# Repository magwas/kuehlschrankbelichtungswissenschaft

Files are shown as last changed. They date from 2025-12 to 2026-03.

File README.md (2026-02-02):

# Kühlschrankbelichtungswissenschaft

Kühlschrankbelichtungswissenschaft means "fridge lighting science".
It is an open hardware, open source steampunk control unit for agriculture projects, with two set of the following features:

- controlled 220V mains plug for a lamp
- humidity sensor as a 3.5mm audio socket
- CO2 sensor
- two temperature sensors
- controlled 12V barrel outlets for ventillation, cooling, nutrient and heating

The CO2 and temperature sensors are connected using RJ11 connectors with the following pinout:

1. GND (green)
2. 3V3 (green-white)
3. SDA (brown)
4. SCL (brown-white)
5. 5V (red)
6. OneWire (red-white)

The ground of the connectors for RJ11 is controlled, as the CO2 sensor used have a fix I2C address.

The circuit design is in the conteroller directory.

The schematics layout looks as it is to make it easier to implement it as a freeform circuit.
This is the reason there is no PCB design. Of course you are welcome to build it on a PCB.
A two-sided PCB should be adequate for the job, there is nothing placement-critical there.

I did not put the USB-c cable between the board and the connector on the chassis on the circuit design,
simply because the symbol I use does not contain it.

## SOFTWARE INSTALLATION

The software uses ESP IDF, and the msglib library.
Install ESP IDF as documented at https://docs.espressif.com/projects/esp-idf/en/latest/esp32/get-started/
Clone msglib to a convenient place, like
```
mkdir ~/build
cd ~/build
git clone https://github.com/magwas/msglib
```

to build, flash and monitor the software, plug in the board to the USB, export MESSAGING_LIB with the location where you cloned it, activate ESP IDF, and run idf.py build, something like

```
export MESSAGING_LIB=$HOME/build/msglib
. ~/.espressif/tools/activate_idf_v5.5.2.sh ~/idf-esp-activate
idf.py -p /dev/ttyACM0 build flash monitor
```

## HARDWARE FABRICATION

The mechanical design is in the FreeCad model box.CFStd. I have a Snapmaker 2, so the CNC jobs use the marlin preprocessor.

The fixjobs.sh script

- fixes the output of the preprocessor (marlin emits M3 S100, snapmaker understands M3 P100, and the comments are in different form)
- removes all Z movement from the laser engraving jobs, replacing some of the to gcode turning the laser off and on again.

IMPORTANT: the engraving job fix translates movement to Z=26 (G0 Z26.000) to turning the laser off, and Z=21 (G0 Z21.000) to turning it on.
Make sure that the heights and depths of the engraving job correspont to these if you modify it.

postprocess all of the CNC jobs. The "Stock Prepare" job is for preparation of the stock on my own machine, you might of course choose other ways to fix your stock.
run fixjobs.sh or something equivalent for your setup.
the file cnc-workflow contains the instructions to do the milling and engraving. It contains the sizes of the stocks. I recommend to use some hardwood. I used white acacia, as I love that wood. You will need a 128x86 and 246x86 mm sheet of 4mm tempered glass.
Populate the dashboard with components. I try to recall here what I was using. Be aware that they are mostly cheap noname parts. Which means you can probably buy ones with similar sizes.

- For the mains plugs, I cannibalized some LEGRAND SUNO plugs, by removing everything above the bottom plastic and metal parts, and trimming down the plastic parts, keeping the tabs which open the electrodes for the assembly.
- The main switch is a 22x30 standard switch.
- The 12V barrel connectors I obtained are for 12mm diameter fine thread. I did not want to buy a tap for that, instead I made the holes the size such that they fit snuggly.
 - Vents are standard PC ventillators
 - The cooling pumps are 12V pumps I bought on eBay. The cooling is a mix of 6mm outer diameter copper and 6mm inner diameter silicone tubes.
 - The nutrient dosage pumps are just like the cooling pumps.
 - I actually do not yet have heating. I plan to coil up some heating wires for that purpose on some ceramics.
- The USB-C connector is a noname one which fits into the 3.5x10mm hole and its length is 15mm. I could not find a datasheet for a similar one.
- The connectors for the humidity sensors are standard 3.5mm audio jacks. They are actually the tye of swinging connector wher the round connector part is fixed to the anti-fracture housing with a thread. I use just the inner part. The humidity sensors are just steel rods (~10cm sut from bicycle spokes) placed 1 cm apart.
- The design now have just a simple hole for the wifi antenna, as I am currently waiting for the board wersion which comes with a connector for it.
- The RJ11 connectors are the plain usual 90 degree ones.

All other components (and most of the aboveones ) are in the BOM of the circuit.

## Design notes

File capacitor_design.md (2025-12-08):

---
mainfont: DejaVu Serif
sansfont: DejaVu Sans
monofont: DejaVu Sans Mono
mathfont: DejaVu Math TeX Gyre
---
###  Geometry & Electrical Performance Summary
The design is based on a wound roll of aluminum foil electrodes separated by paper dielectric, with a target capacitance of 10 µF and a foil width of 0.3 meters. The required physical dimensions change significantly based on the paper thickness and the composite dielectric constant (εᵣ ≈ 3.2) of the oil-impregnated paper.

| Parameter | Using 30 g/m² Paper (~40 µm thick) | Using 60 g/m² Paper (~75 µm thick) | Notes |
| :--- | :--- | :--- | :--- |
| **Foil Length Required** | ~47 meters | ~88 meters | For one of the two foil strips. |
| **Approx. Outer Diameter** | ~6.3 cm | ~11.2 cm | Estimated from winding volume around a 1 cm core. |
| **Estimated Safe DC Voltage** | **300 - 400 V** | **550 - 750 V** | **Critical:** This is a *practical safe voltage*, estimated at 20-30% of the material's theoretical limit to account for imperfections. |
| **Material Breakdown Strength** | Up to **30 kV/mm** (theoretical) | | Conservative estimate for well-impregnated, dry paper-oil composite. The oil displaces air and can increase breakdown strength significantly. |

###  Preparation & Treatment Steps
The process is divided into three main phases, with the CaO treatment being a highly experimental and challenging addition.

1.  **Core Construction & Drying**
    *   **Wind the Capacitor:** Assemble the dry, unimpregnated roll using the specified lengths of aluminum foil and paper.
    *   **Condition the Roll:** Bake the entire wound roll in an oven at 105-110°C for several hours to drive out absorbed moisture. Cool it in a dry environment.

2.  **Oil Treatment with CaO (Experimental & High-Risk)**
    *   **Purpose:** To chemically bind residual water in the olive oil (**CaO + H₂O → Ca(OH)₂**) and neutralize free fatty acids.
    *   **Critical Challenge:** The reaction creates a fine, insoluble **Calcium Hydroxide [Ca(OH)₂]** powder suspended in the viscous oil, which is extremely difficult to remove completely.
    *   **Recommended Separation Method:** **Vacuum Filtration** with a **filter aid** (like diatomaceous earth) is the most effective practical method. Simple decantation will not work, and centrifugation may be insufficient.
    *   **Major Risk:** Any remaining Ca(OH)₂ in the oil can dissociate into conductive ions, severely degrading the dielectric's insulating properties and likely ruining the capacitor.

3.  **Final Impregnation & Sealing**
    *   Immediately after drying, submerge the capacitor roll in the treated, warm olive oil in a vacuum chamber (or as close to a vacuum as possible) to ensure the oil fully penetrates the paper layers.
    *   Seal the impregnated capacitor in an airtight container to prevent moisture re-absorption.

###  Key Takeaways & Recommendations
*   **Trade-off:** Thicker paper (60 g/m²) allows for a much higher voltage rating but results in a capacitor that is nearly twice as large.
*   **Voltage is Theoretical:** The calculated safe voltages are optimistic estimates. Real-world performance depends entirely on the perfection of your drying, impregnation, and sealing.
*   **CaO is Problematic:** The CaO treatment step introduces significant complexity and risk of failure. For a more reliable project, the recommended alternatives are to use a **non-contact "tea bag" method** with silica gel (desiccant) and calcium carbonate (acid scavenger), or to use a purpose-made dielectric fluid like transformer oil.

Glass pipe: https://webaruhaz.lombik.hu/uvegcsovek?product_id=1785

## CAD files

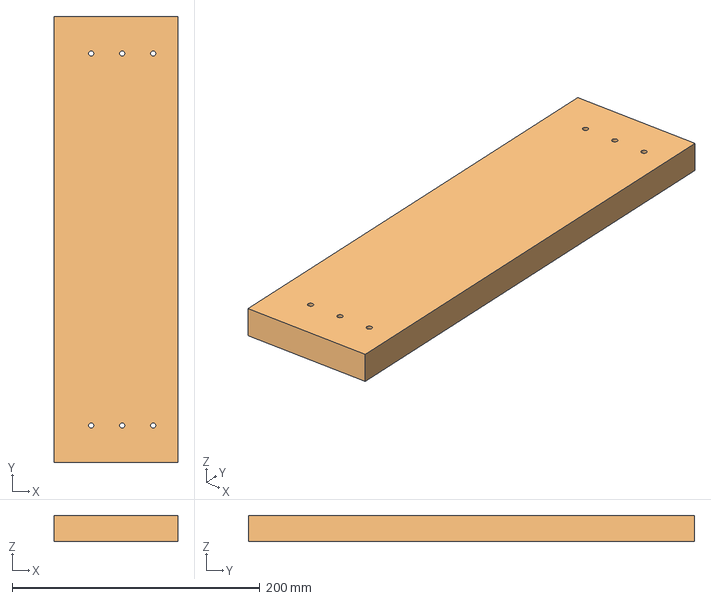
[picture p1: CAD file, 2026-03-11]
box.FCStd
100.0 x 360.0 x 21.0 mm
Stock-The Stock004
Stock-The Stock006

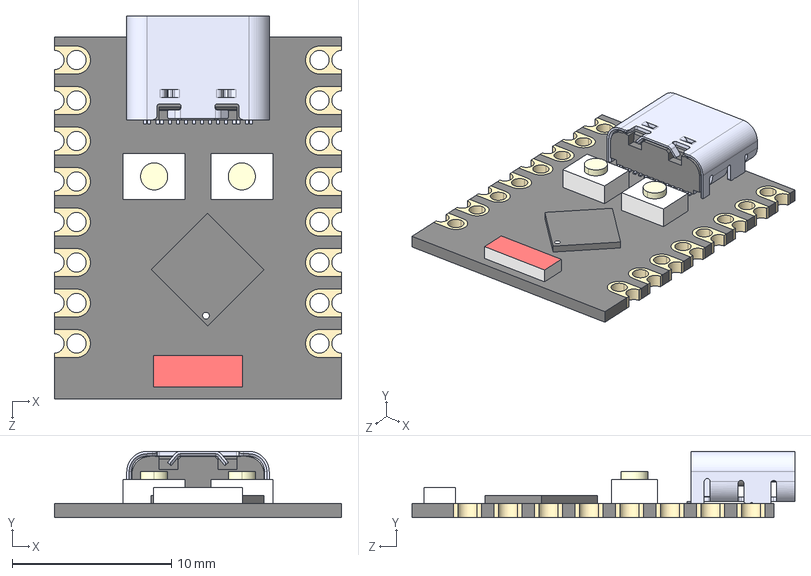
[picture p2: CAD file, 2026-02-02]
controller/parts/ESP32-C3_SUPERMINI_TH.step
18.0 x 4.16 x 24.0 mm
Board c3mini
USB C
components (other)^ESP32-C3 SuperMini

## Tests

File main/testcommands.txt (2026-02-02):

astable 1 -1 4
astable 0 -1 1
astable 1 0 10
astable 2 0 1000
astable 3 0 1000
astable 5 0 10
astable 6 0 0
astable 0 0 1

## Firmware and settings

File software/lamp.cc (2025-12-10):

#include <Arduino.h>
#include "lamp.h"
#include "userinterface.h"

void Lamp::setPPF(int ppf65, int ppf18) {
  if(!isLampOn)
    Lamp::on();
  Lamp::setPPF65(ppf65);
  Lamp::setPPF18(ppf18);
}

void Lamp::setlamp(int port, float ppf) {
  int value = ppf*PPF2DUTYCYCLE_MULTIPLIER;
  char buffer[PAYLOAD_LENGTH];
  sprintf(buffer,"setting %u to %f (%u)",port,(double)ppf,value);
  systemQueue.send(MessageType::Console,buffer);
  analogWrite(port,value);
}

void Lamp::setPPF18(int ppf18) {
  if(ppf18>PPF18_MAX)
    ppf18 = PPF18_MAX;
  if(ppf18>=PPF_MIN*4) {
    float perlamp = ppf18/4.0;
      setlamp(PWM_18_1,perlamp);
      setlamp(PWM_18_2,perlamp);
  } else {
      setlamp(PWM_18_1,ppf18/2.0);
      setlamp(PWM_18_2,0);
  }
}


void Lamp::setPPF65(int ppf65) {
  if(ppf65>PPF65_MAX)
    ppf65 = PPF65_MAX;
  if(ppf65>=PPF_MIN*5) {
    float perlamp = ppf65/5.0;
      setlamp(PWM_65_1,perlamp);
      setlamp(PWM_65_2,perlamp);
      setlamp(PWM_65_3,perlamp);
  } else if(ppf65>=PPF_MIN*4) {
    float perlamp = ppf65/4.0;
      setlamp(PWM_65_1,perlamp);
      setlamp(PWM_65_2,perlamp);
      setlamp(PWM_65_3,0);
  } else if(ppf65>=PPF_MIN*3) {
    float perlamp = ppf65/3.0;
      setlamp(PWM_65_1,perlamp);
      setlamp(PWM_65_2,0);
      setlamp(PWM_65_3,perlamp);
  } else if(ppf65>=PPF_MIN*2) {
    float perlamp = ppf65/2.0;
      setlamp(PWM_65_1,perlamp);
      setlamp(PWM_65_2,0);
      setlamp(PWM_65_3,0);
  } else  {
      setlamp(PWM_65_1,0);
      setlamp(PWM_65_2,0);
      setlamp(PWM_65_3,ppf65);
  }
}

void Lamp::on() {
  analogWrite(PWM_65_1,0);
  analogWrite(PWM_65_2,0);
  analogWrite(PWM_65_3,0);
  analogWrite(PWM_18_1,0);
  analogWrite(PWM_18_2,0);
  digitalWrite(LAMP_RELAY,HIGH);
  for(int i=0;i< 256;i++){
    analogWrite(PWM_MAINS,i);
    delay(20);
  }
  isLampOn = 1;
}

void Lamp::off() {
  digitalWrite(LAMP_RELAY,LOW);
  for(int i=255;i>=0;i--){
    analogWrite(PWM_MAINS,i);
    delay(20);
  }
  delay(1000);

  analogWrite(PWM_65_1,0);
  analogWrite(PWM_65_2,0);
  analogWrite(PWM_65_3,0);
  analogWrite(PWM_18_1,0);
  analogWrite(PWM_18_2,0);
  isLampOn = 0;
}

void Lamp::setCommand(Message *msg) {
    CommandPayload *payload = (CommandPayload *)msg->payload;
    lamp.setPPF(payload->arg1,payload->arg2);
}

void Lamp::relayCommand(Message *msg) {
    CommandPayload *payload = (CommandPayload *)msg->payload;
    digitalWrite(LAMP_RELAY,HIGH);
    delay(payload->arg1);
    digitalWrite(LAMP_RELAY,LOW);
}

void Lamp::onOffCommand(Message *msg) {
    CommandPayload *payload = (CommandPayload *)msg->payload;
    switch(payload->arg1) {
        case 0:
            lamp.off();
            break;
        case 1:
            lamp.on();
            break;
        default:
            systemQueue.send(MessageType::Console,"0: off, 1:on");
    }
}

Lamp::Lamp() {
    systemQueue.registerListener(MessageType::Set,&setCommand);
    systemQueue.registerListener(MessageType::Relay,&relayCommand);
    systemQueue.registerListener(MessageType::Lamp,&onOffCommand);
}
Lamp lamp;

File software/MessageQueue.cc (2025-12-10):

#include "MessageQueue.h"
#include <string.h>

void spinlock_enter(volatile int *lock) {
    (*lock)++;
    while(1!=(*lock));
}
void spinlock_exit(volatile int *lock) {
    (*lock)--;
}

void MessageQueue::send(Message *messageP) {
    spinlock_enter(&messageInProgress);
    int oldTail = messageQueueTail;
    messageQueueTail = (messageQueueTail+1)%MSG_QUEUE_LENGTH;
    memcpy(&(messageQueue[oldTail]),messageP,sizeof(Message));
    spinlock_exit(&messageInProgress);
}

void MessageQueue::send(MessageType type, char value) {
    spinlock_enter(&messageInProgress);
    int oldTail = messageQueueTail;
    messageQueueTail = (messageQueueTail+1)%MSG_QUEUE_LENGTH;
    messageQueue[oldTail].type=type;
    messageQueue[oldTail].payload[0]=value;
    spinlock_exit(&messageInProgress);
}

void MessageQueue::send(MessageType type, const char* value) {
    spinlock_enter(&messageInProgress);
    int oldTail = messageQueueTail;
    messageQueueTail = (messageQueueTail+1)%MSG_QUEUE_LENGTH;
    messageQueue[oldTail].type=type;
    memcpy(messageQueue[oldTail].payload,value,PAYLOAD_LENGTH);
    spinlock_exit(&messageInProgress);
}

void MessageQueue::send(MessageType type, const __FlashStringHelper* value) {
    spinlock_enter(&messageInProgress);
    int oldTail = messageQueueTail;
    messageQueueTail = (messageQueueTail+1)%MSG_QUEUE_LENGTH;
    messageQueue[oldTail].type=type;
    memcpy_P(messageQueue[oldTail].payload,value,PAYLOAD_LENGTH);
    spinlock_exit(&messageInProgress);
}

void MessageQueue::send(MessageType type, float value) {
    spinlock_enter(&messageInProgress);
    int oldTail = messageQueueTail;
    messageQueueTail = (messageQueueTail+1)%MSG_QUEUE_LENGTH;
    messageQueue[oldTail].type=type;
    *((float*) (messageQueue[oldTail].payload))=value;
    spinlock_exit(&messageInProgress);
}

void MessageQueue::send(MessageType type, int value) {
    spinlock_enter(&messageInProgress);
    int oldTail = messageQueueTail;
    messageQueueTail = (messageQueueTail+1)%MSG_QUEUE_LENGTH;
    messageQueue[oldTail].type=type;
    ((int *)messageQueue[oldTail].payload)[0]=value;
    spinlock_exit(&messageInProgress);
}

Message* MessageQueue::receive() {
    if(messageQueueTail == messageQueueHead)
        return NULL;
    while(messageInProgress!=0);
    int oldHead = messageQueueHead;
    messageQueueHead = (messageQueueHead+1)%MSG_QUEUE_LENGTH;
    return &(messageQueue[oldHead]);
}

int MessageQueue::registerListener(MessageType type,Listener listener) {
    for(int i=0;i<LISTENERS_COUNT_MAX;i++) {
        if(listeners[i].type==MessageType::None) {
            listeners[i].type = type;
            listeners[i].listener = listener;
            return i;
        }
    }
    return -1;
}

int MessageQueue::unregisterListener(MessageType type,Listener listener) {
    for(int i=0;i<LISTENERS_COUNT_MAX;i++) {
        if(listeners[i].type==type && listeners[i].listener == listener) {
            listeners[i].type = MessageType::None;
            return i;
        }
    }
    return -1;
}
int MessageQueue::dispatch(Message *msg) {
    int count = 0;
    for(int i=0;i<LISTENERS_COUNT_MAX;i++) {
        if(listeners[i].type==msg->type) {
            (*(listeners[i].listener))(msg);
            count++;
        }
    }
    return count;
}

MessageQueue systemQueue;

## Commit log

2025-11-08 initial checkin
    [controller.kicad_pcb, controller.kicad_sch, led.kicad_pcb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]
2025-11-08 deleted unused schematic files
    [leds.kicad_sch, power.kicad_sch, relays.kicad_sch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]
2025-11-10 made symbols and footprint relative to project
    [B7B-PH-K-S.step, ESP32-S3-DEVKITC-1-N8R8.step, IPS70R1K4P7SAKMA1.stp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]
2025-11-15 schematics with 5050 leds ready
    [ESMR401VSN102MA50S.stp, G6DN-1A_DC4.5.stp, HCTI-220-5.8.stp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]
2025-11-16 using single and dual top switch current driver circuits
    [G6DN-1A_DC5.stp, LM2903P.stp, led.kicad_sch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]
2025-11-17 RTC added
    [BAT-HLD-005-THM.stp, MCP7940N-I_P.stp, led.kicad_sch]
2025-11-17 led pcb designed
    [SMCJ1.5KE440A-TP.stp, led.kicad_pcb, leds18k_1.kicad_sch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]
2025-11-19 changed measurement resistor in current driver
    [led.csv, top_switch.kicad_sch]
2025-11-20 NDBG504F3950B1F thermistor calibration data and temperature calculation
2025-11-20 dumped soil humidity sensor design to soilHumidity.cc
2025-12-08 top switch, capacitor design doc
    [TLP240A_F.stp, top_switch.kicad_sch]
2025-12-15 compile errors, battery backup, restruct
    - compile errors on lack of #defines
    - clock battery backup configured
    - 1sec interrupt moved to clock, housekeep runs on message
    - console messages instead of printfs
2025-12-19 moved device drivers and services to library
2025-12-19 relayed lamp project started
2026-01-17 box design
    [box.FCStd]
2026-01-17 engraving of all labels
    [box.FCStd]
2026-01-25 new version of box
    [box.FCStd]
2026-01-25 jobs for all box parts, job fixer update
    [box.FCStd]
2026-01-30 CNC workflow, job fixes
    [box.FCStd]
2026-01-30 through jobs go through
    [box.FCStd]
2026-01-30 jack holes
    [box.FCStd]
2026-01-30 stock prepare, same origo
    [box.FCStd]
2026-01-30 4.2 clearance holes for stock
    [box.FCStd]
2026-01-30 tags in profiles
    [box.FCStd]
2026-01-30 purging unused symbols and footprints
    [B7B-PH-K-S.step, BAT-HLD-005-THM.stp, ESMR401VSN102MA50S.stp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]
2026-01-30 deleted all schematics, they are outdated and never realized
    [controller.kicad_sch, led.kicad_pcb, led.kicad_sch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]
2026-02-02 wider space for glasses and mains plug rods, humidity sensor body
    [box.FCStd]
2026-02-18 fixed bottom part and CAM jobs
    [box.FCStd]
2026-02-18 Tags fixed on bottom plate
    [box.FCStd]
2026-02-18 More beefy tags on all perimeter profiles
    [box.FCStd]
2026-02-26 updated relays and 250V part with actual circuit
    [250V.kicad_sch, relays.kicad_sch]
2026-02-26 glass slots redesigned to be 5mm wide
    They are recentered to be 2mm from both sides.
    Hopefully this will be wide enough for my 4mm+painting test glass
    closes: #1
    [box.FCStd]
2026-03-11 CAM job checking and preparation
    There are check for the cam operations to make sure no regression happens.
    All the following is checked and fixed in the model:
    - dressup tags size
    - output file name
    - profile final depth
    - pocket pattern and step over ( closes: #2)
    - tool speeds
    - generally the existence and parameters of each operation compared to a baseline
    There is also a macro to save and fix the gcode to the jobs directory.
    [box.FCStd]
2026-03-11 fix RJ11 profile, fixup script confusion
    Changed the last RJ11 operation to profile the whole hole in one run. fixes: #3
    there was a naming confusion and save_cam_operations macro was missing. fixed than up
    [box.FCStd]
2026-03-11 RJ11 pocket extension
    added extension to RJ11 pockets. closes: #4
    [box.FCStd]
2026-03-11 screw head pockets
    closes: #6
    [box.FCStd]
2026-03-11 Antenna hole correct diameter
    closes: #8
    [box.FCStd]
2026-03-11 Engraving of console label fixed
    fixes: #7
    [box.FCStd]
